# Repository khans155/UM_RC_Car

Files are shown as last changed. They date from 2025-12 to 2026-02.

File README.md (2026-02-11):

# Universal (AC Series) Motor Powered RC Car (Work in Progress)
<p align="center">
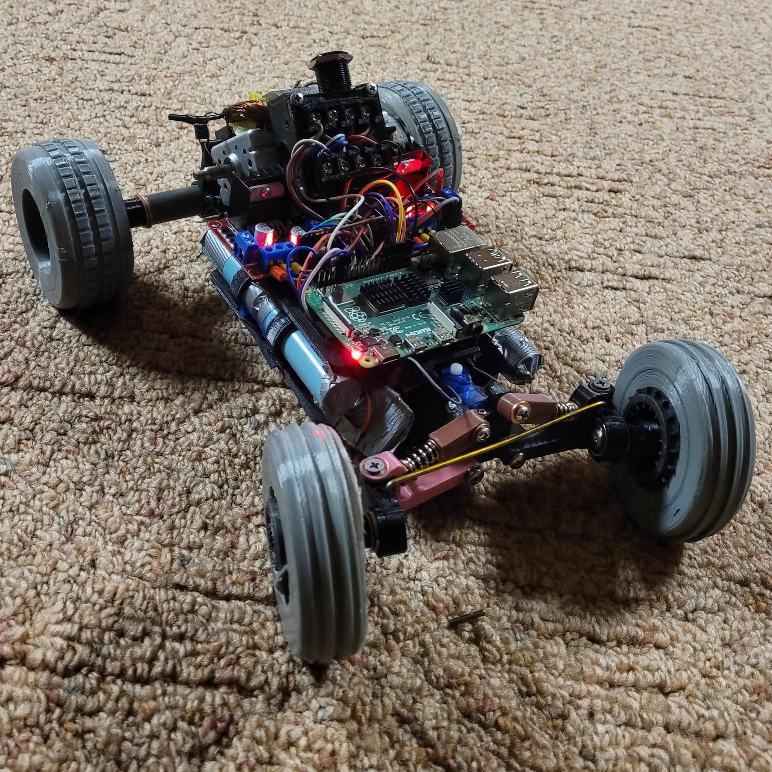
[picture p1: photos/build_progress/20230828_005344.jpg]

  </p>

What motivated me to attempt this project was learning how universal motors are wired. Their wiring allows them to operate on both AC and DC power sources due to the stator and rotor windings being connected in series, though due to this you can't control its direction. However, when these windings are supplied separately from a DC source, it becomes possible to control torque and speed independently. This capability is especially beneficial in situations where high torque is required, such as when a vehicle is stuck against an obstacle and needs additional torque to overcome it.
  
## Motor Control System
The motor control system consists of:
- Two high-current motor driver boards  
- An ESP32 microcontroller  
- A FlySky FS-IA10B receiver and FlySky Remote
- An AC series motor (separate stator and rotor windings)  
- Servo motors for steering  

One motor driver controls the stator windings, while the second driver controls the rotor windings. The ESP32 acts as the control interface between the FlySky receiver and the motor drivers, translating remote inputs into motor speed, torque, and direction commands.
<p align="center">
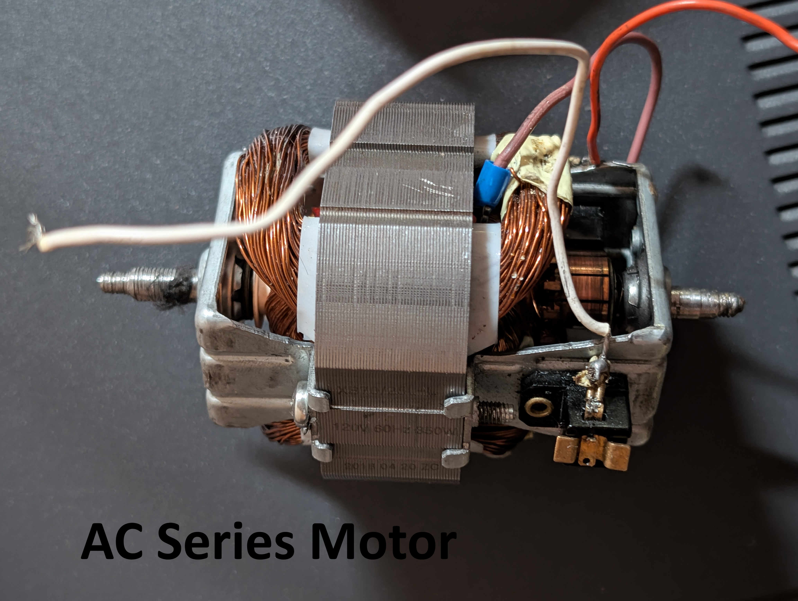
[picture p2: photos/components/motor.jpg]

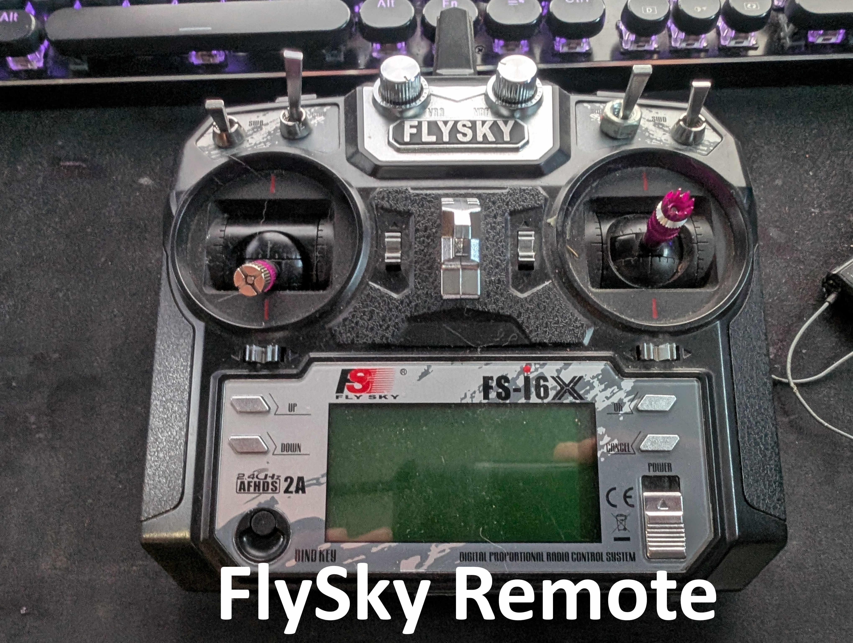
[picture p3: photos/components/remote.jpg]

</p>

The initial design used an L298N motor driver, rated for 3 A. This driver was insufficient for delivering the current required for the speed/torque of the AC series motor for this project.

To address this, the L298N was replaced with the **BTS7960 motor driver**, which is rated for up to 43 A.

Two BTS7960 drivers are used for:
- **Driver 1:** Controls power delivered to the stator windings (torque control)
- **Driver 2:** Controls power and direction of the rotor windings (speed and direction control)

Both drivers are powered by a 25 V Li-ion battery pack.

---

### Rotor Windings (Speed & Direction)
- Primary control of motor speed and direction  
- Direction control via **control pins 40 and 42**
- Speed controlled using a **PWM signal on pin 44** generated by the ESP32

### Stator Windings (Torque Control)
- Used to control motor torque independently of speed
- At low speeds, higher power is supplied to increase torque
- At higher speeds, stator power is reduced to limit current draw

This approach enables independent control of **torque and rotational speed**.
<p align="center">
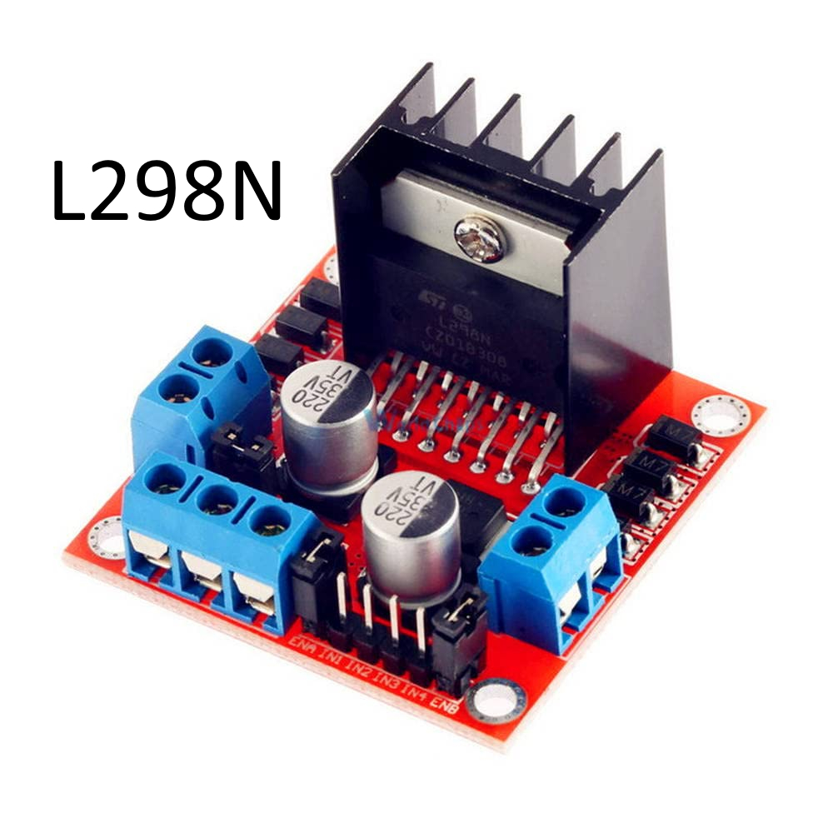
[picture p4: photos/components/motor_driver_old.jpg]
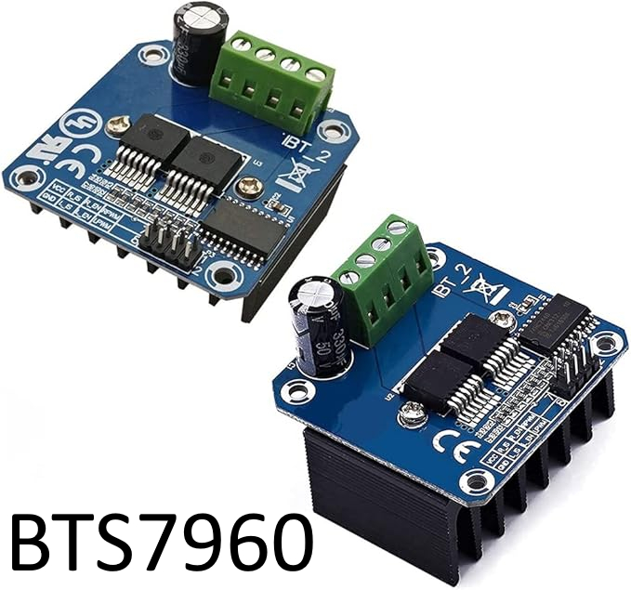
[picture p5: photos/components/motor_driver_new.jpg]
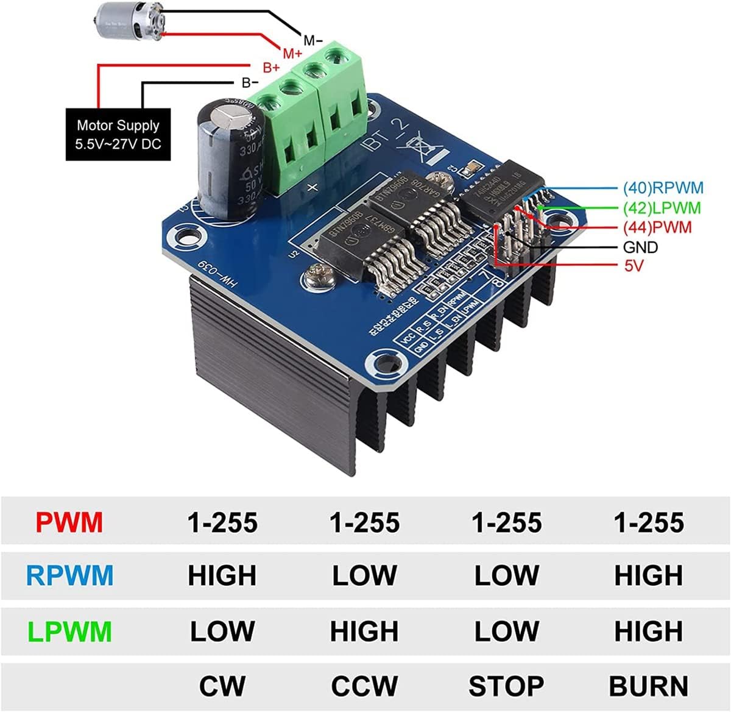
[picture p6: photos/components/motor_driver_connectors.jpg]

</p>

---

The initial system architecture used a Raspberry Pi 4 as an intermediary between the radio receiver and the motor drivers. This was later replaced with an ESP32, as the Raspberry Pi’s additional processing capability and operating system overhead were unnecessary for a real-time motor control application, and also because I fried the Raspberry Pi :). The ESP32 provides a simpler and more deterministic control platform while still offering sufficient performance for signal decoding and PWM generation.

The ESP32 is programmed to receive iBUS serial data from a FlySky FS-IA10B 10-channel 2.5 GHz receiver, which supports both individual PWM outputs and a serial iBUS interface. Communication over this protocol is handled using the IBusBM library. Serial communication is initialized using IBus.begin(Serial2, 1), where pin 1 of the ESP32 is connected to the receiver’s iBUS output.

The FlySky transmitter is configured to transmit the throttle signal on channel 2 of the iBUS stream. This signal is decoded by the ESP32 and converted into appropriate PWM duty cycles for the stator and motor drivers. Channel 5 is mapped to a switch on the transmitter and is used to control motor direction. The ESP32 continuously monitors this channel and reverses motor direction when the switch state changes by actuating the motor driver connected to the rotor windings.

Servo motors are connected directly to the FlySky receiver, as they accept standard PWM signals and therefore do not require any intermediate signal translation.

<p align="center">
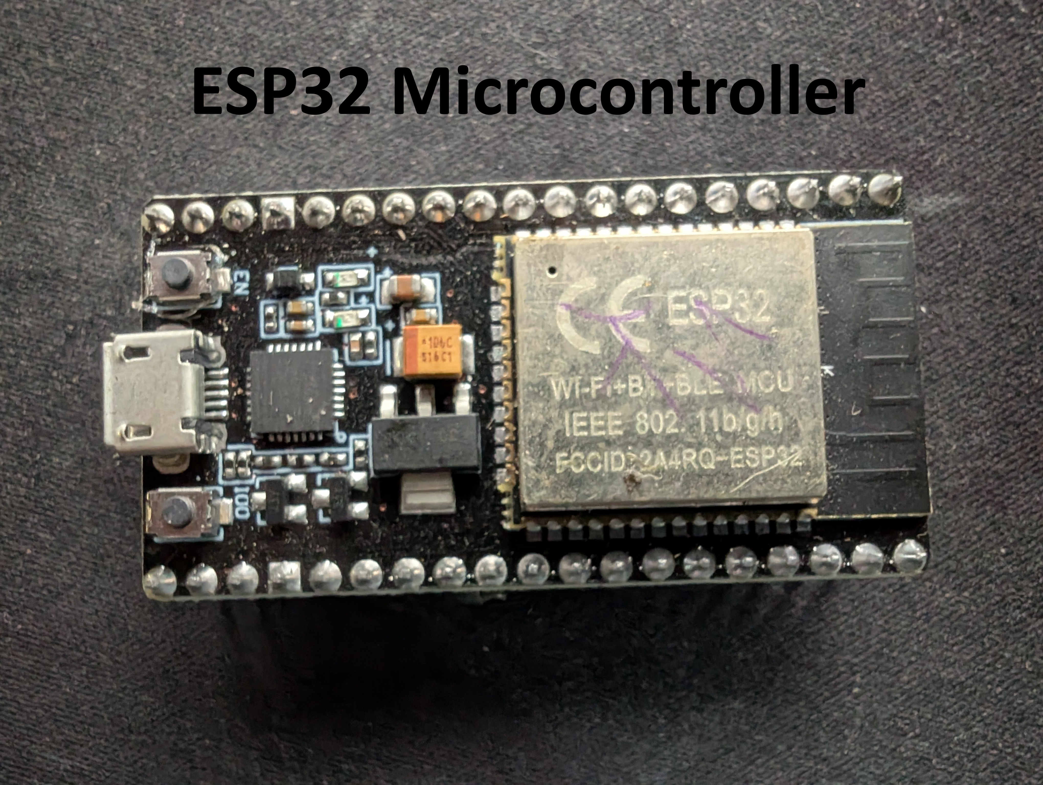
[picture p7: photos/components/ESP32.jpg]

</p>

## Power System (Batteries, Voltage Regulator)
<p align="center">
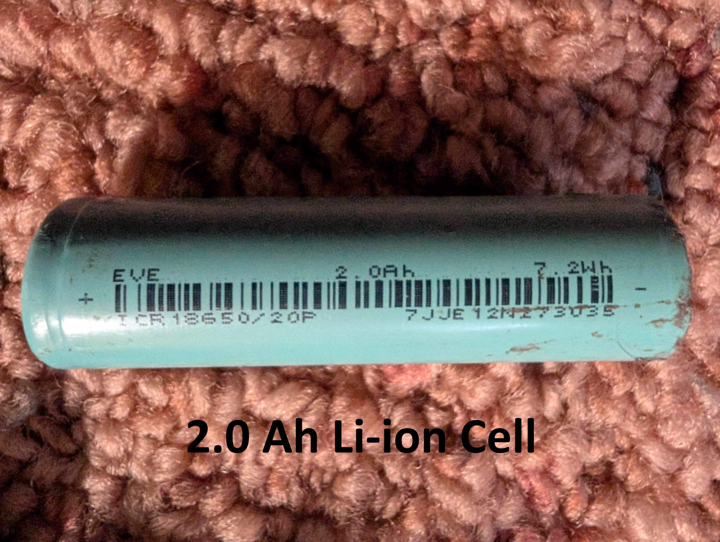
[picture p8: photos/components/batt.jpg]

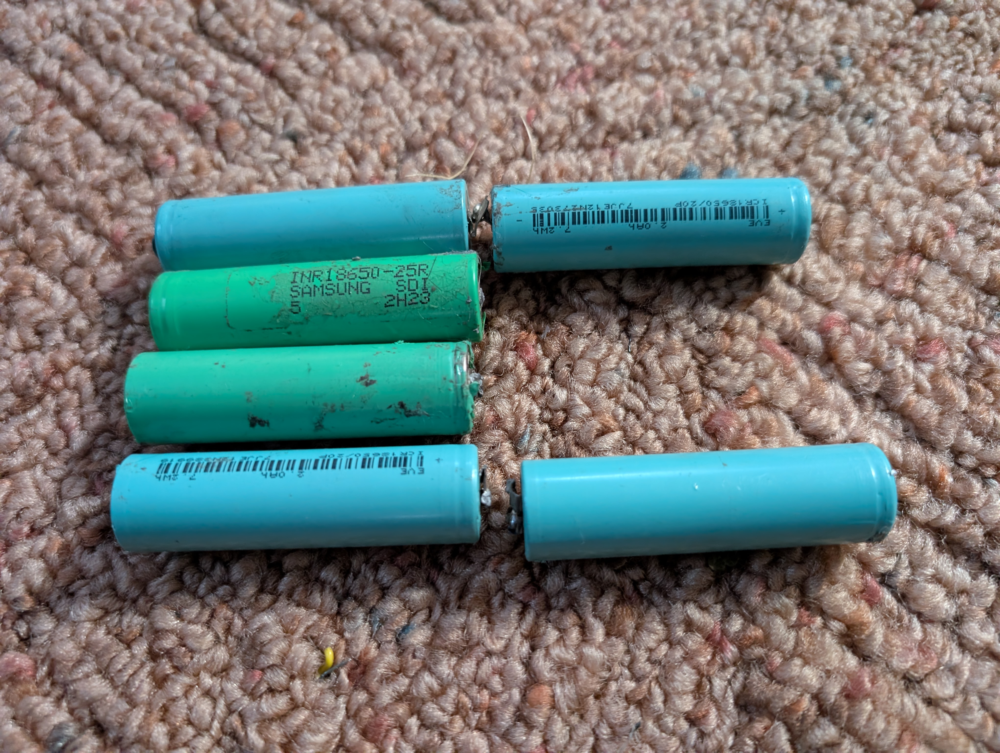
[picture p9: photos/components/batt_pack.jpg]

</p>

<p align="center">
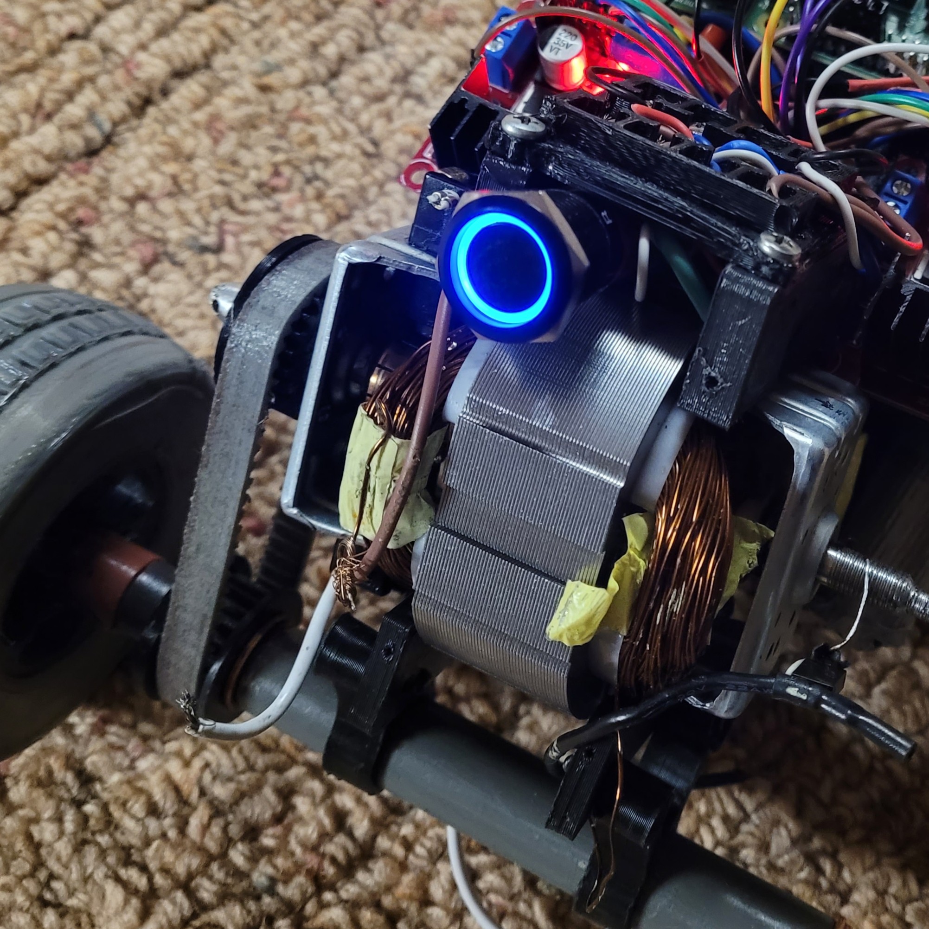
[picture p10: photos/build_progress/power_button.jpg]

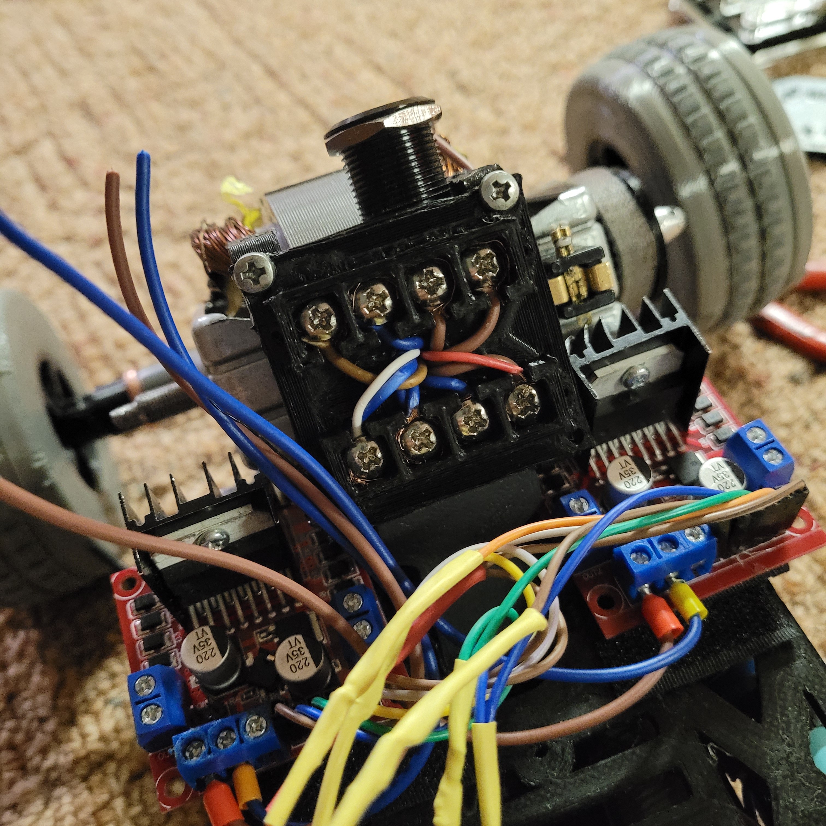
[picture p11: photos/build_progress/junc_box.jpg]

</p>

## 3D Design and Fabrication
<p align="center">
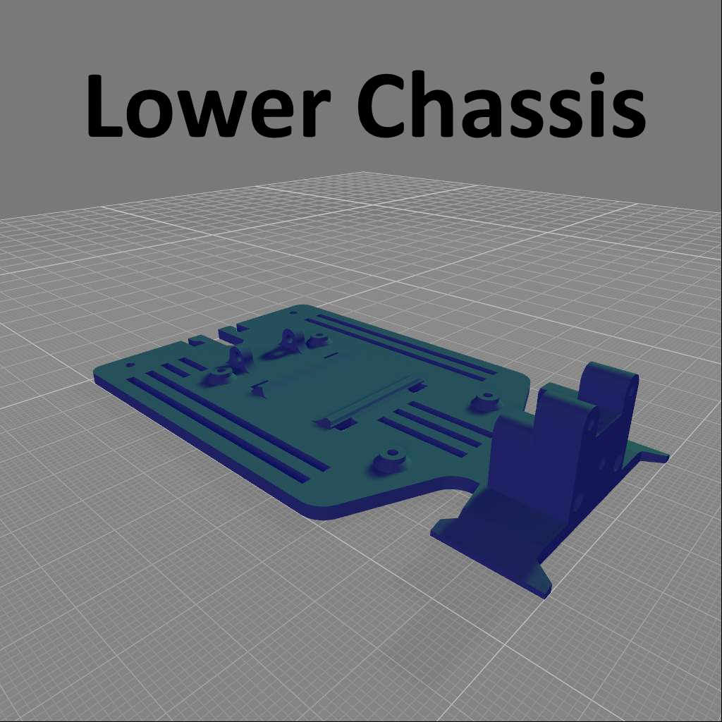
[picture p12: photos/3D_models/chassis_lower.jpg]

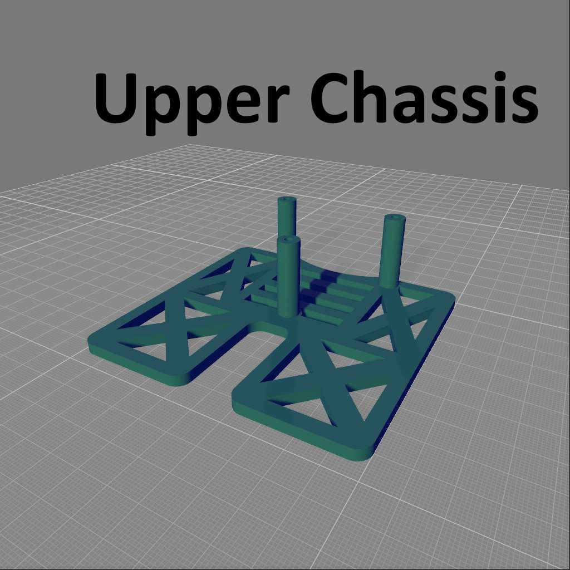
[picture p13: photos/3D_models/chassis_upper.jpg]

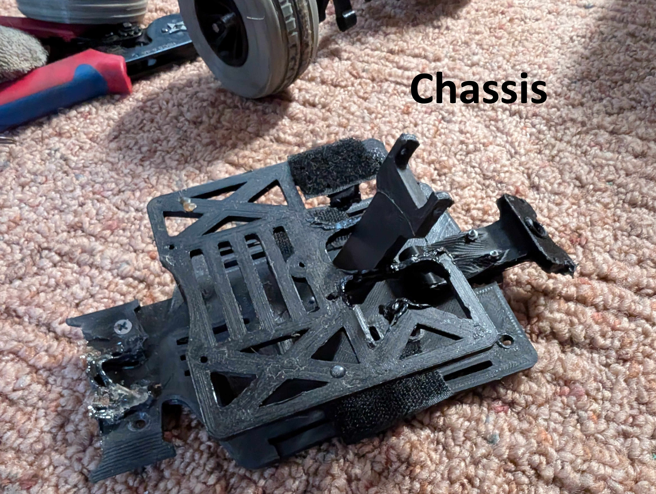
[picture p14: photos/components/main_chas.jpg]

</p>

<p align="center">
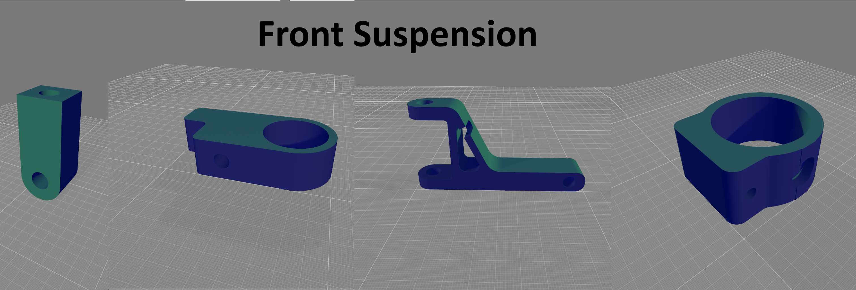
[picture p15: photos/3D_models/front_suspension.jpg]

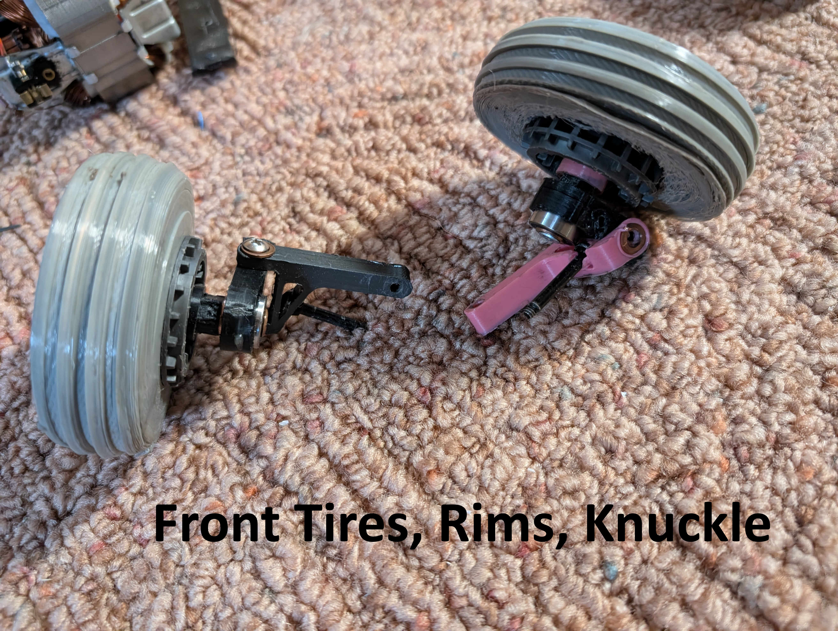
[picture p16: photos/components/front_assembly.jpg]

</p>

<p align="center">
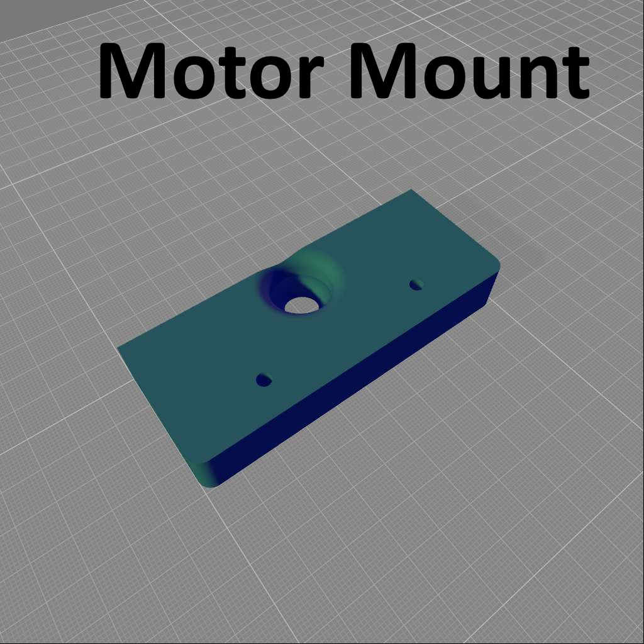
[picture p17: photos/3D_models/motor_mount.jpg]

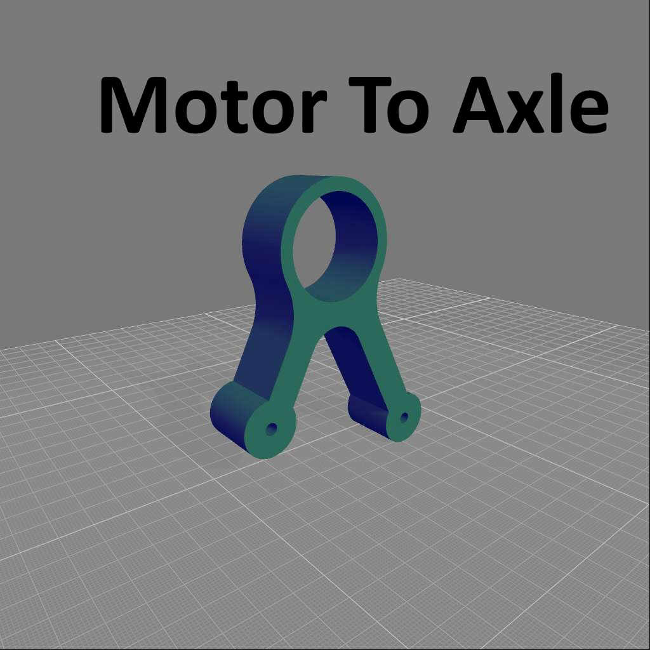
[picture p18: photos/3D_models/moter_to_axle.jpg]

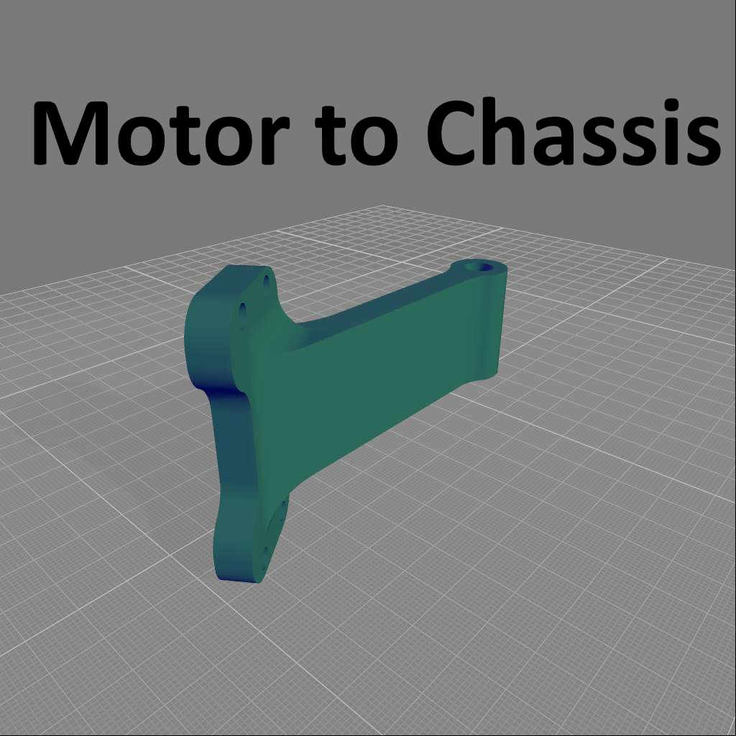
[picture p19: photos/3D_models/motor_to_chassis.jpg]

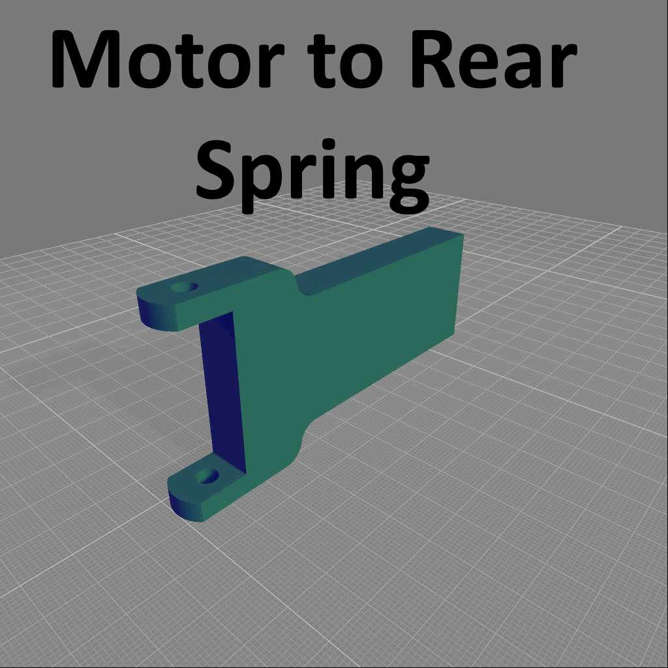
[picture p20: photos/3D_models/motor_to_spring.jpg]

</p>

<p align="center">
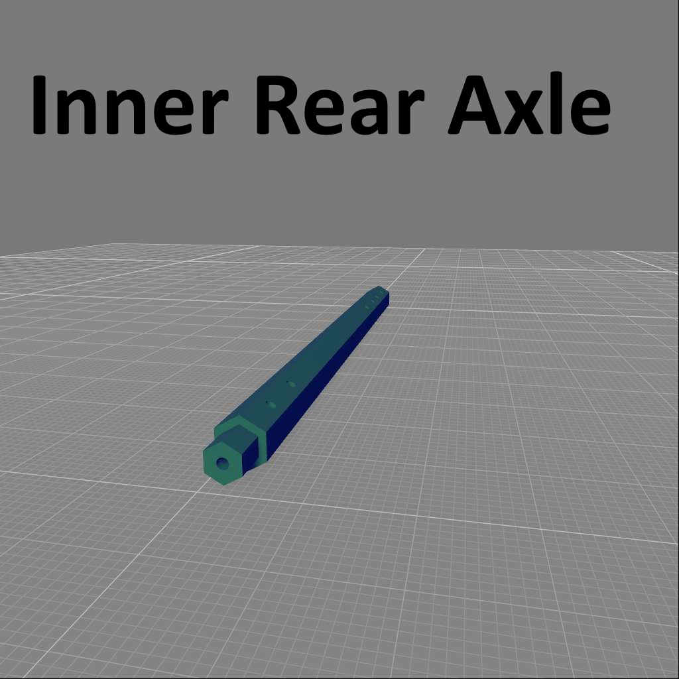
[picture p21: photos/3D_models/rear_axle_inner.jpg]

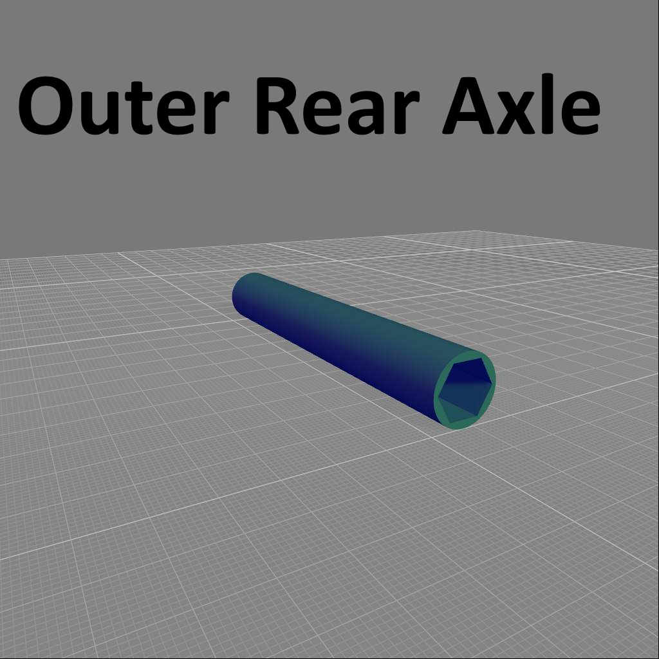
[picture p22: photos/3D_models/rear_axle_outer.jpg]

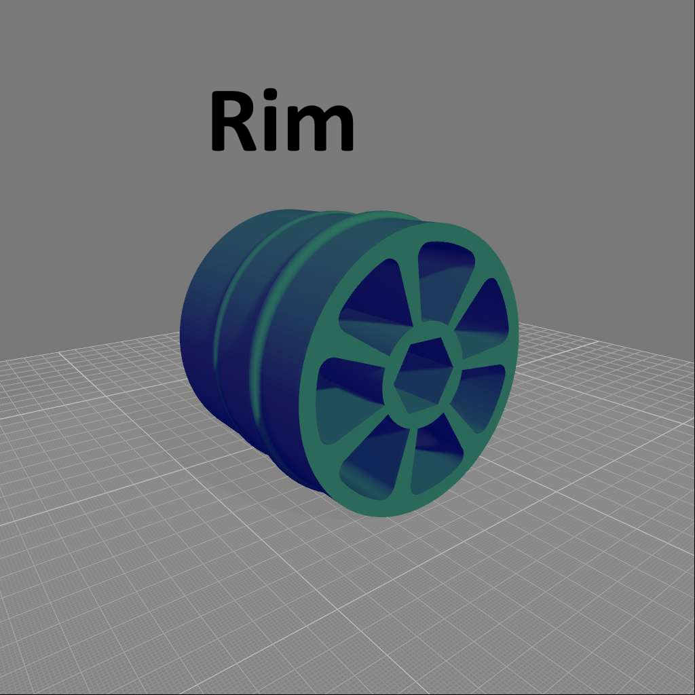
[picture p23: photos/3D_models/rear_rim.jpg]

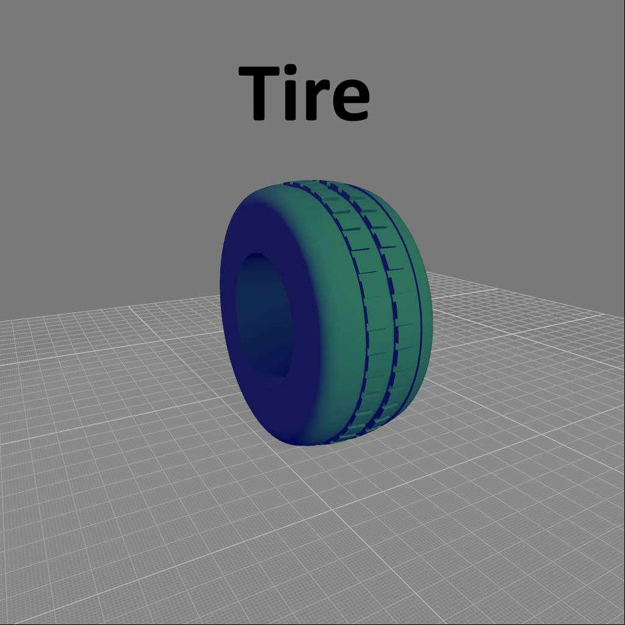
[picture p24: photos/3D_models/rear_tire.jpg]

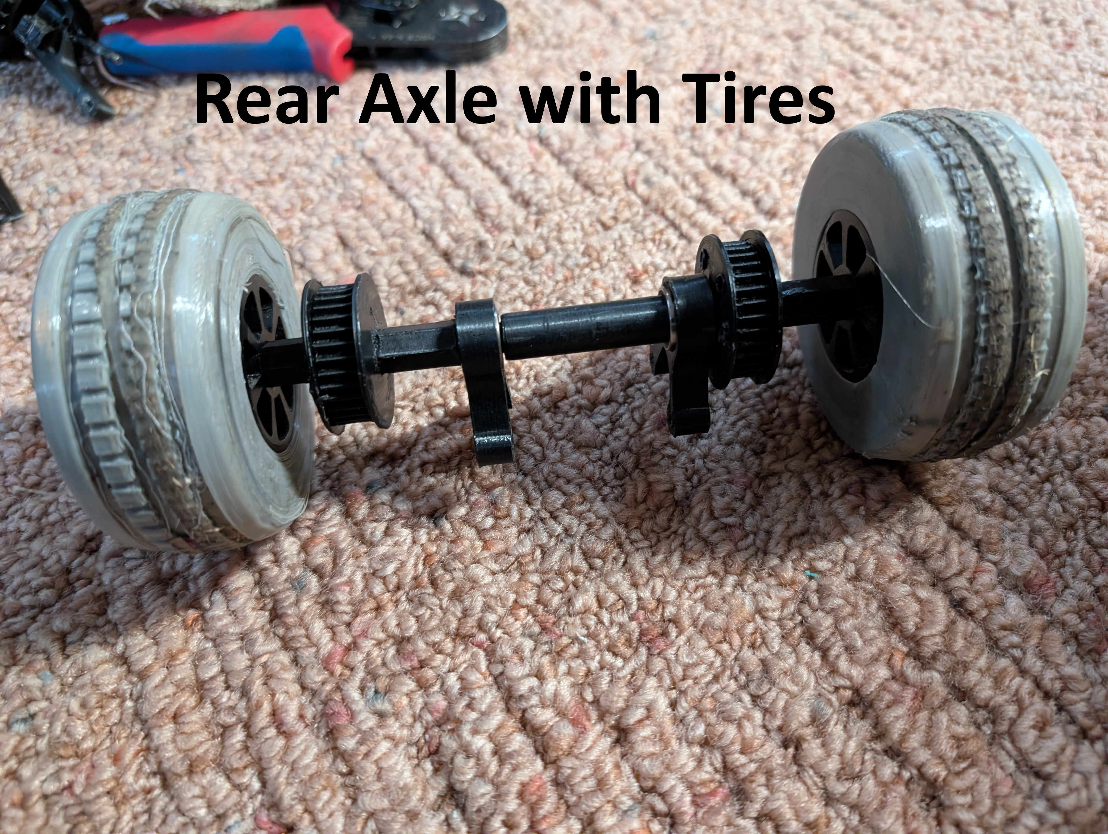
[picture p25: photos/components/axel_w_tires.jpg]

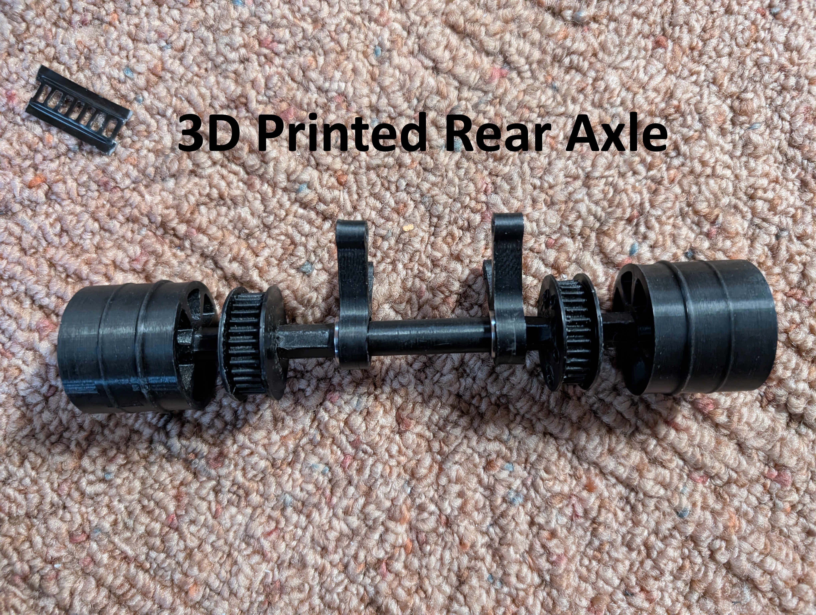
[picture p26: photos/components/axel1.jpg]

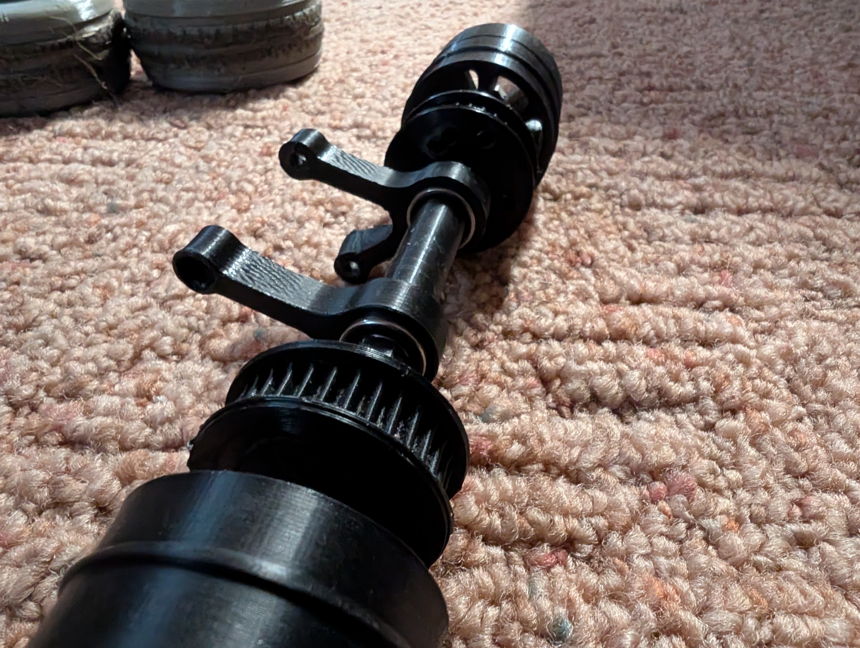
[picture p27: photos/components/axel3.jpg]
  
</p>

<p align="center">
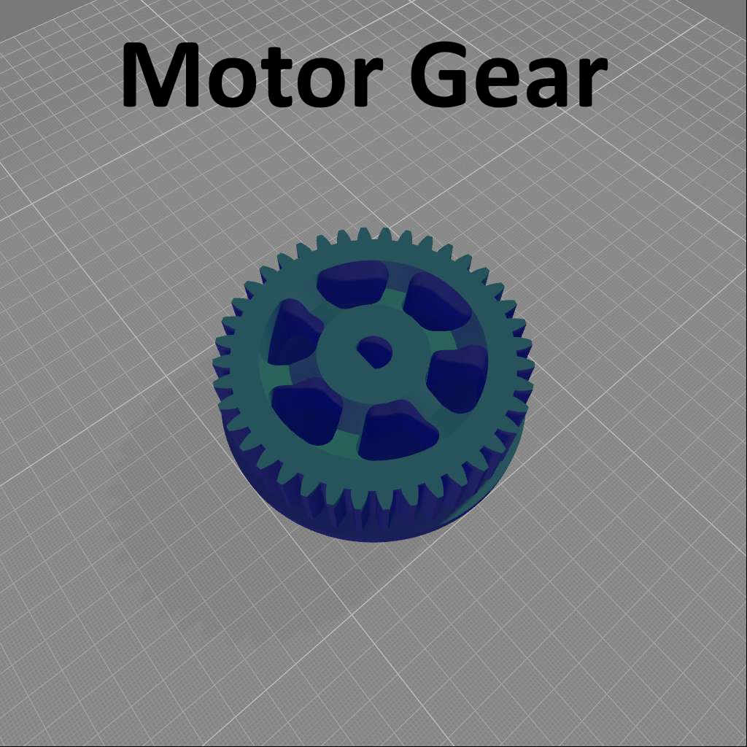
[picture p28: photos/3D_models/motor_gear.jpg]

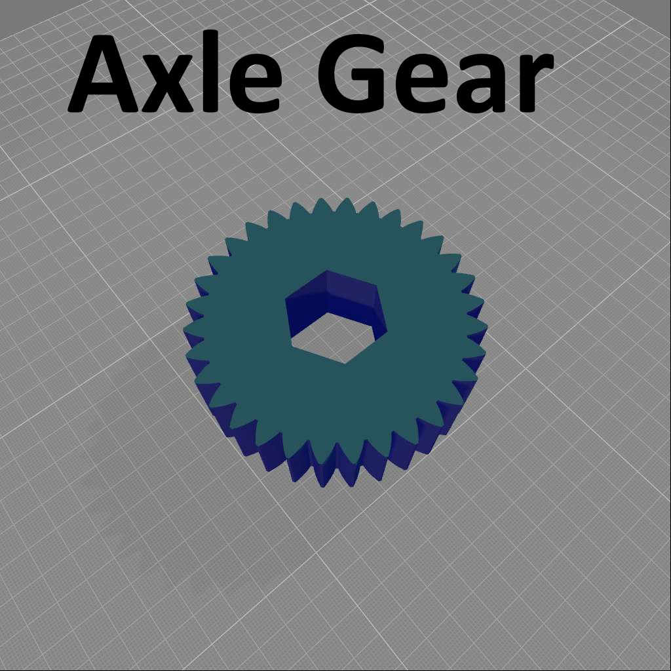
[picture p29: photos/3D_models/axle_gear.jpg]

</p>

## Progress Photos
<p align="center">


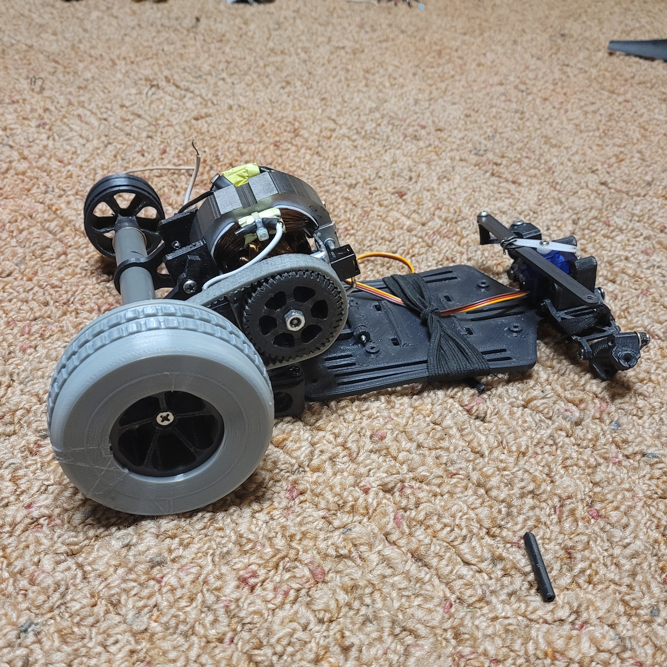
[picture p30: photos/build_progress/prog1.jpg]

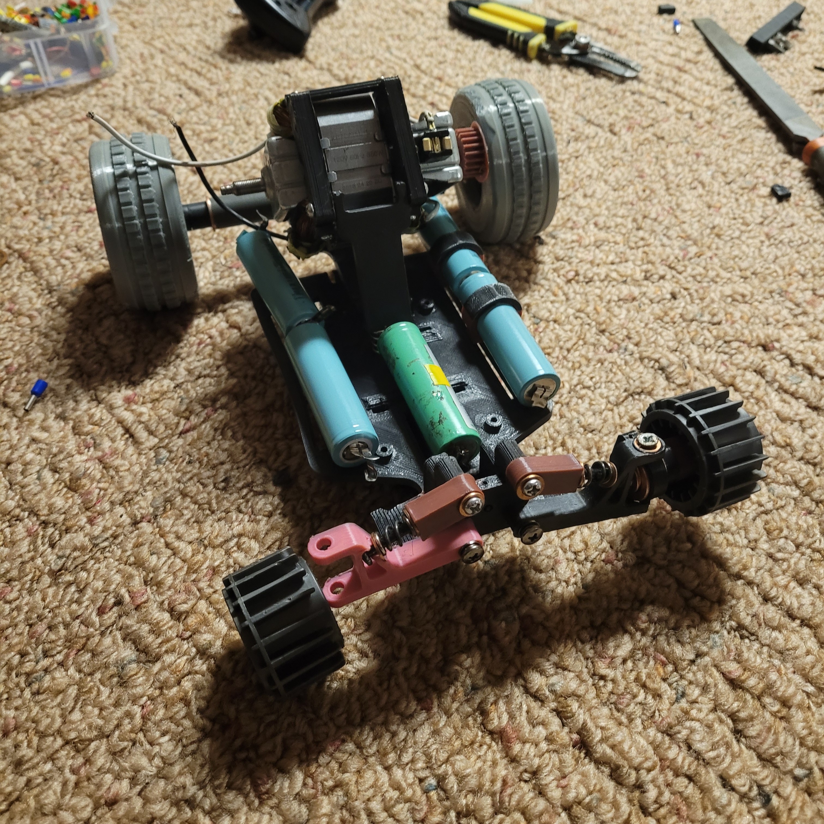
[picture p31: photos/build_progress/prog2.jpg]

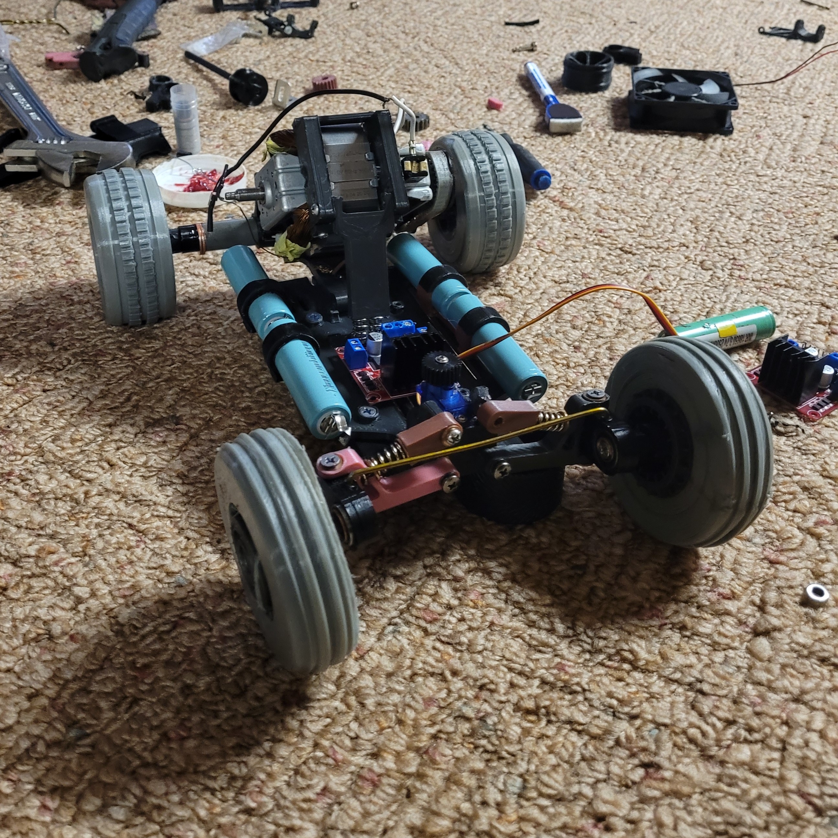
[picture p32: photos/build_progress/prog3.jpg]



</p>

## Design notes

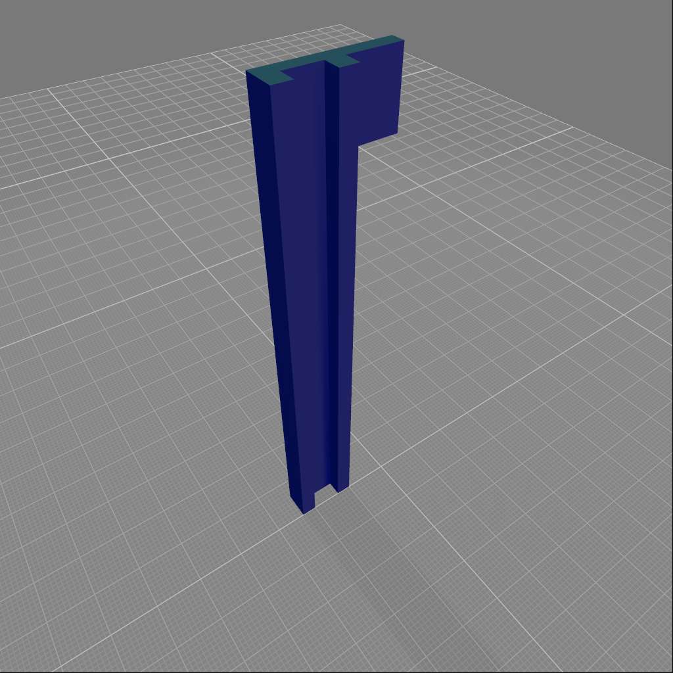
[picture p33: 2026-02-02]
photos/3D_models/chassis_reinforcement.jpg

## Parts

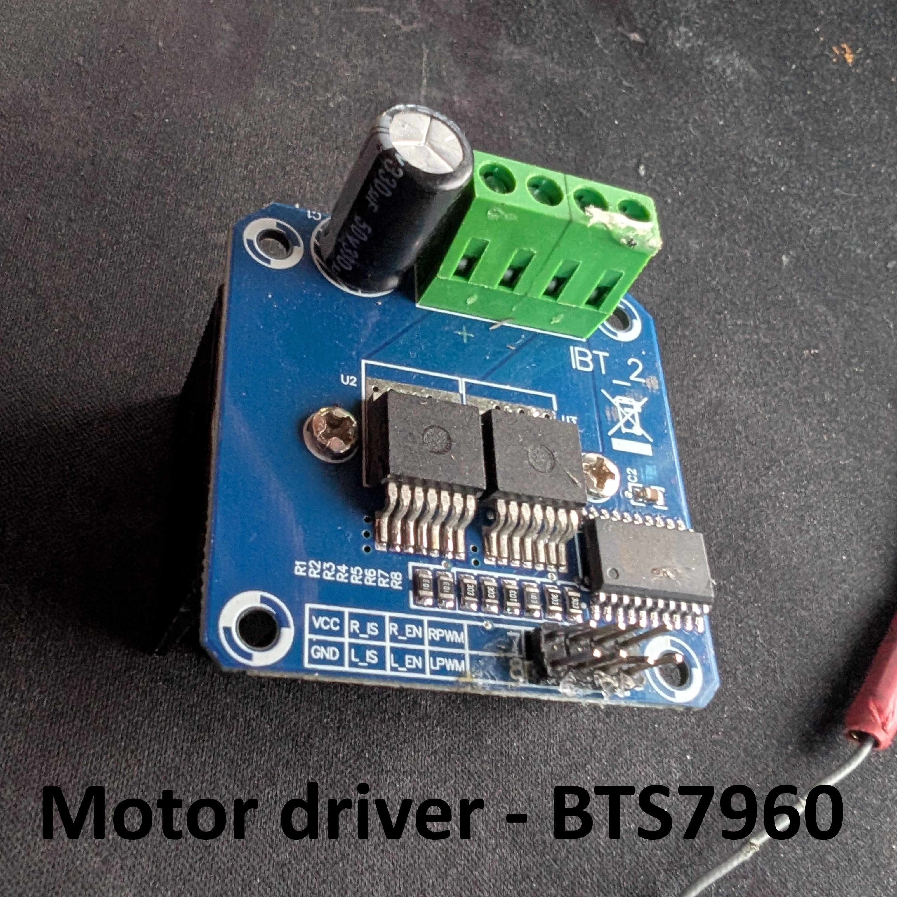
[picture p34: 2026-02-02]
photos/components/motor_driver.jpg

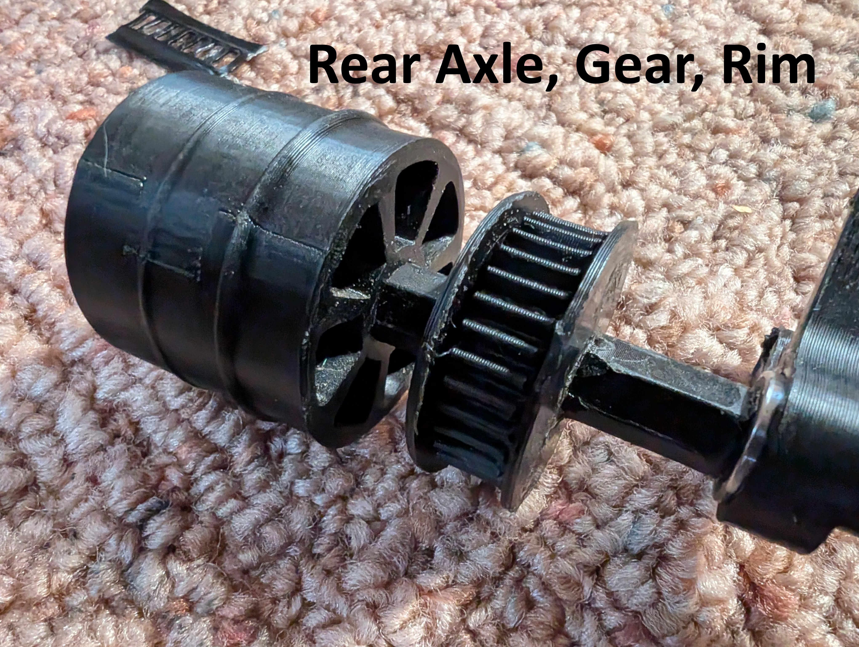
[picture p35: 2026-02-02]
photos/components/axel2.jpg

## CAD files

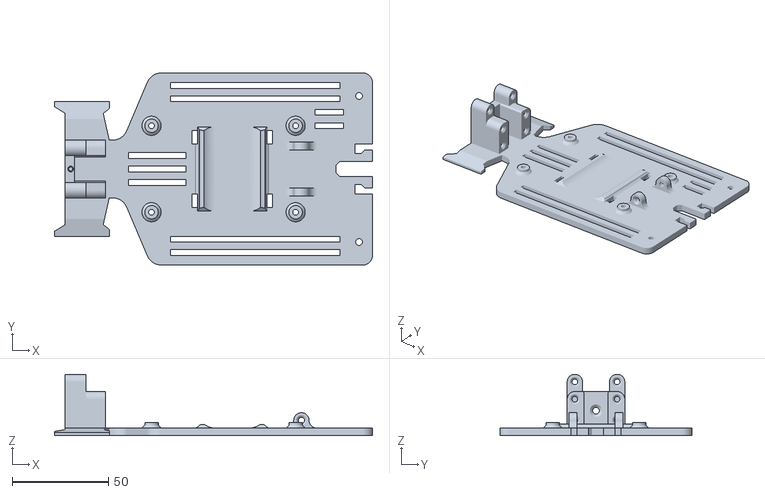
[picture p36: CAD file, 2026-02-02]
3d_models/chassis_lower.stl
165.5 x 100.0 x 32.0

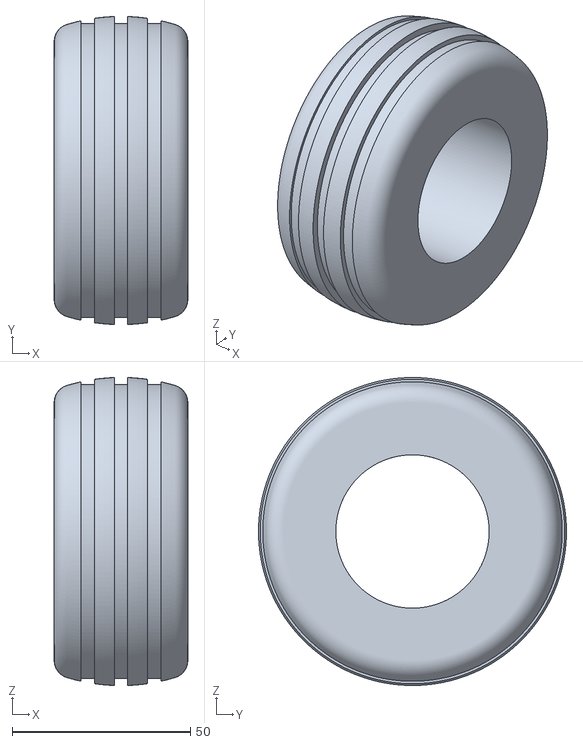
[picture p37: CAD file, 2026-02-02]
3d_models/front_tire.stl
37.5 x 86.4 x 86.4

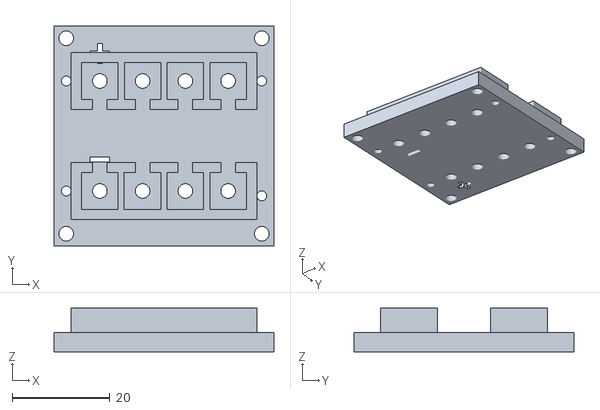
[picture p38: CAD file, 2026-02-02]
3d_models/junction_box.stl
45.0 x 45.0 x 9.00

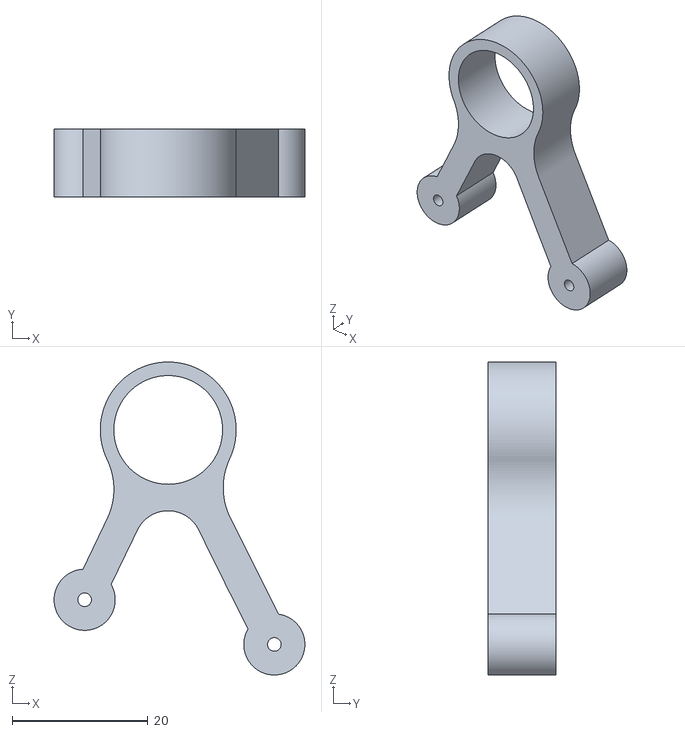
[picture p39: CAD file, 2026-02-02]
3d_models/motor_to_axle.stl
36.9 x 10.0 x 46.1

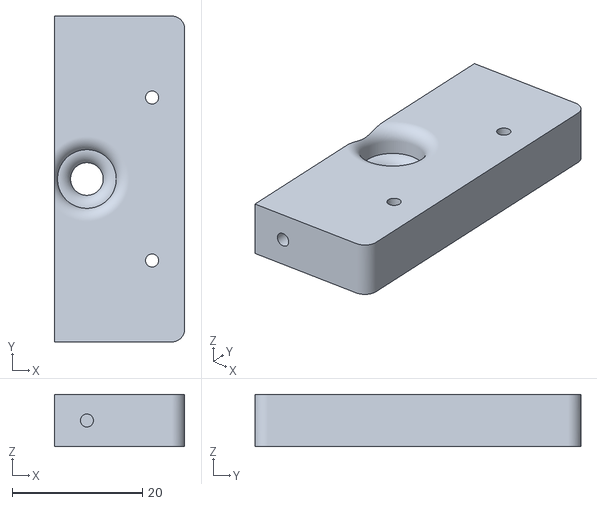
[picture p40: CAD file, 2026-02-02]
3d_models/motor_mount.stl
20.0 x 50.0 x 8.00

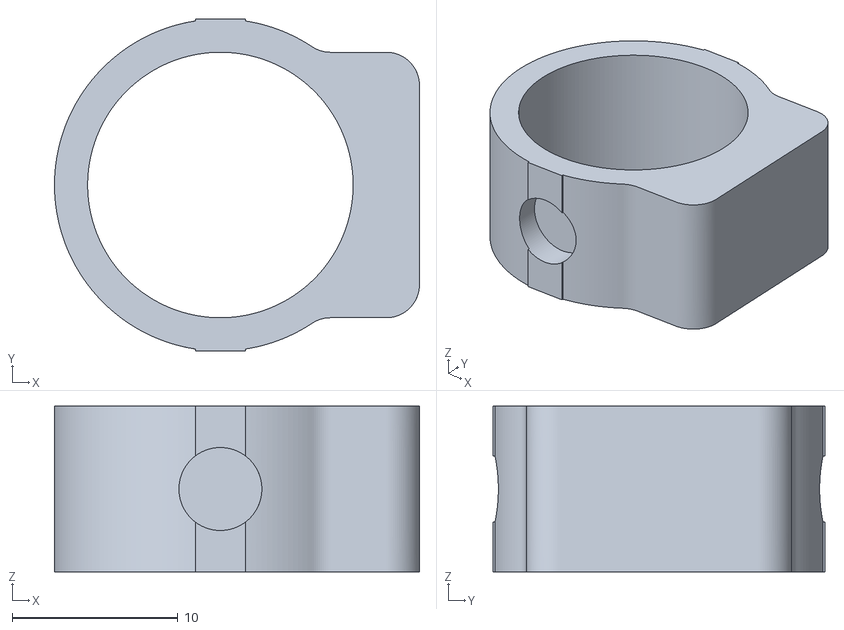
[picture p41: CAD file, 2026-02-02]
3d_models/front_suspension_3.stl
22.0 x 20.0 x 10.0

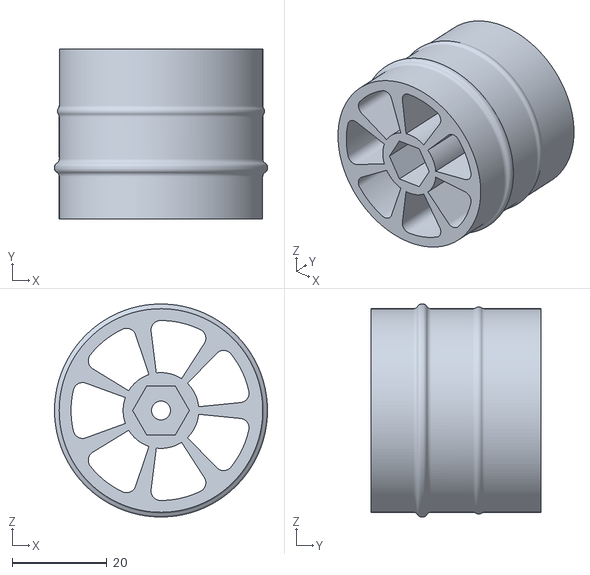
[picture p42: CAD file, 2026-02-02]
3d_models/rim.stl
45.0 x 36.0 x 45.0

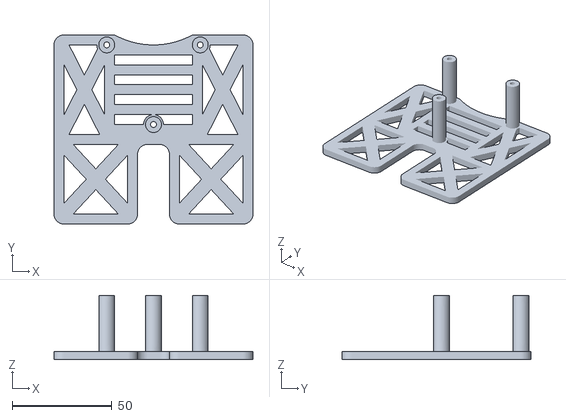
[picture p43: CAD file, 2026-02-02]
3d_models/chassis_upper.stl
100.0 x 95.0 x 32.2

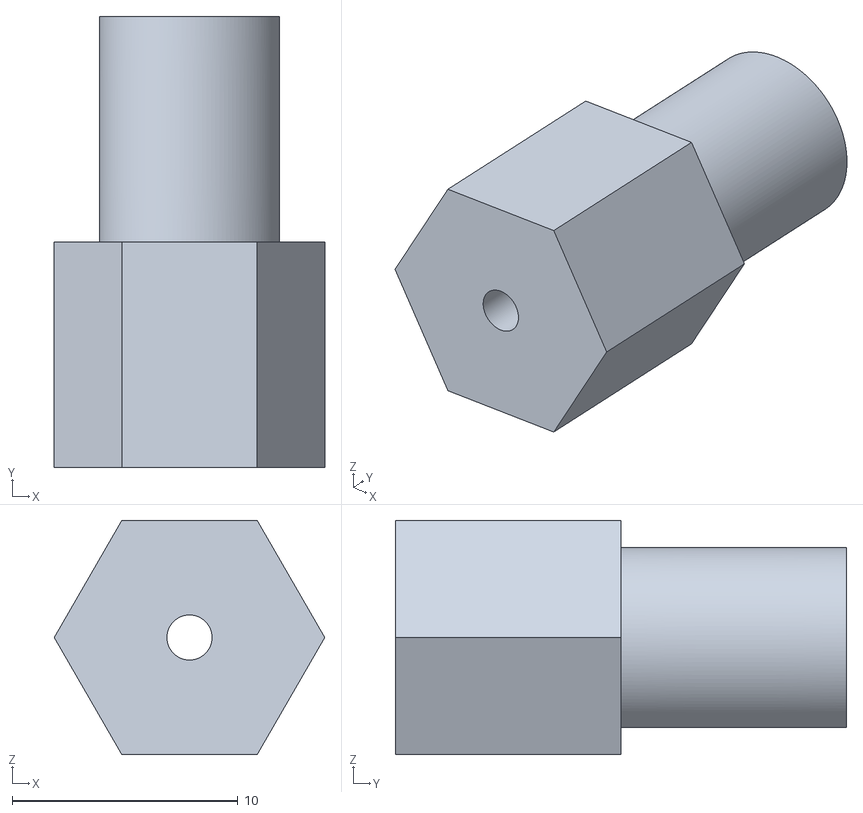
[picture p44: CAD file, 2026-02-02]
3d_models/front_axle.stl
12.0 x 20.0 x 10.4

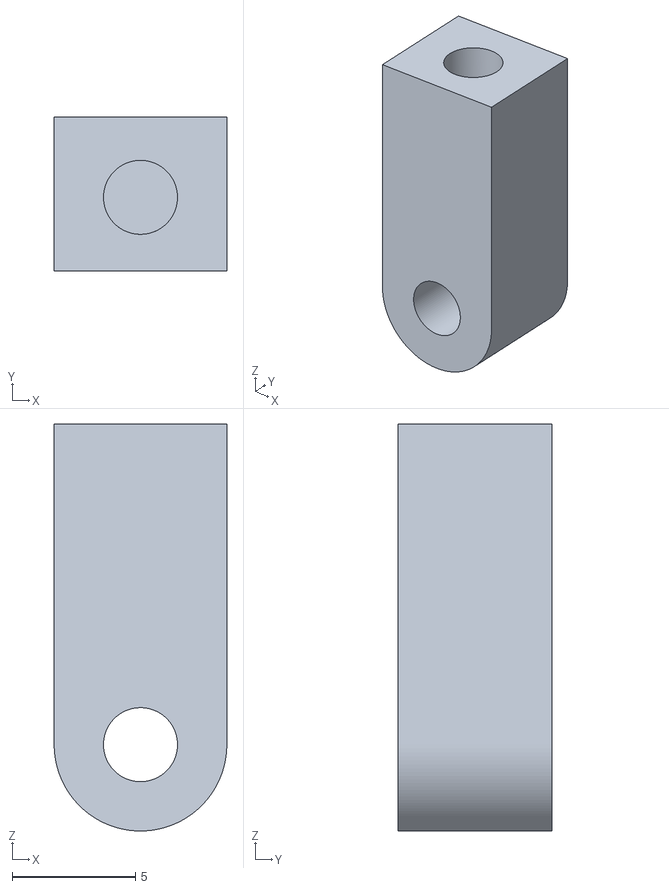
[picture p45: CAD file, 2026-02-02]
3d_models/suspension_to_spring.stl
7.00 x 6.25 x 16.5

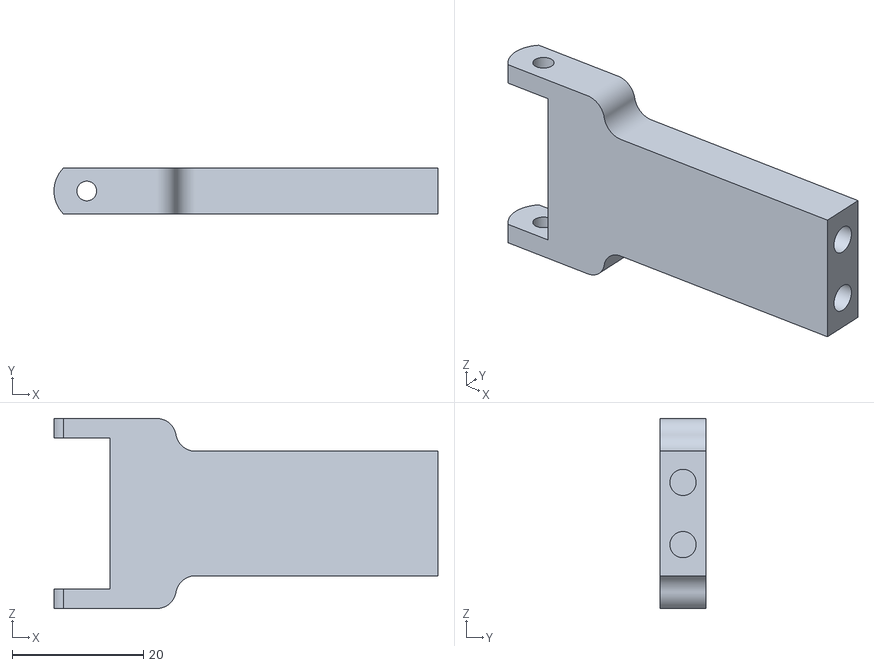
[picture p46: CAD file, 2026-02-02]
3d_models/motor to spring.stl
58.6 x 7.00 x 29.0

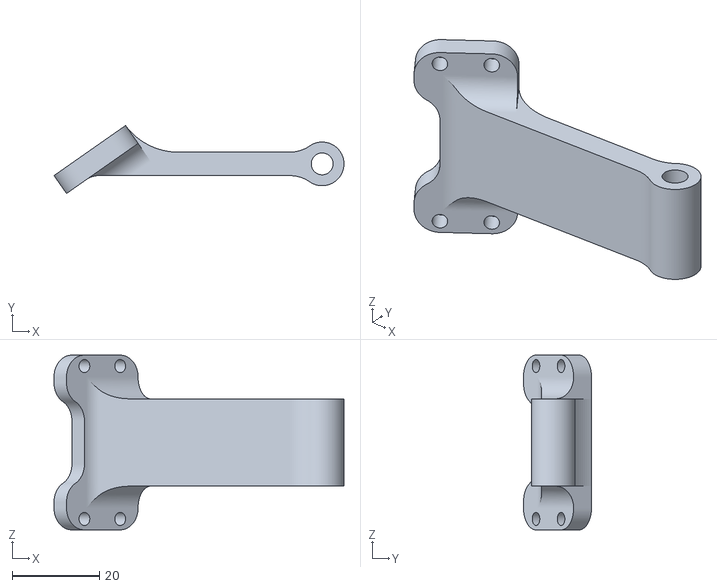
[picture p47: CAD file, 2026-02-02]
3d_models/motor to frame.stl
66.4 x 15.6 x 40.0

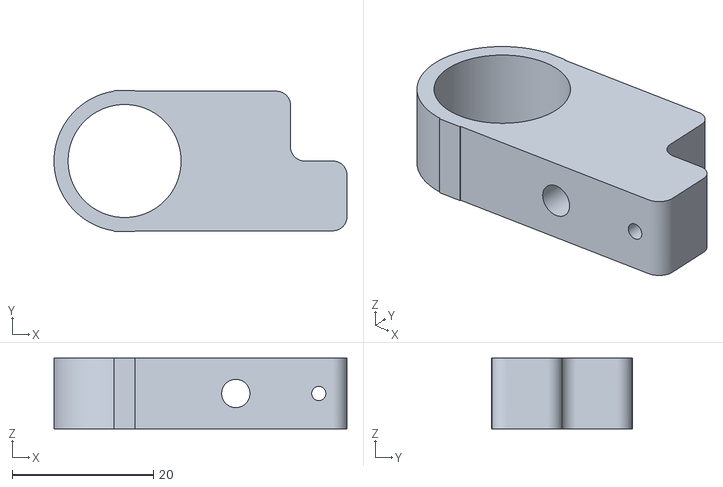
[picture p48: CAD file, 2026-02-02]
3d_models/front_suspension_1.stl
41.5 x 20.0 x 10.0

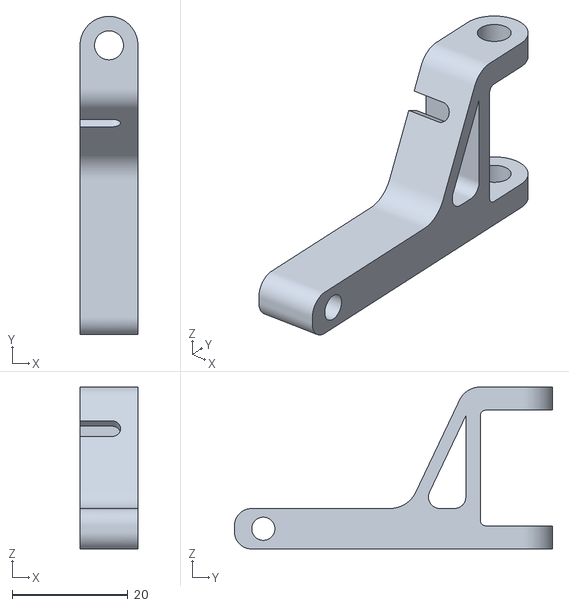
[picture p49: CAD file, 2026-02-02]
3d_models/front_suspension_2.stl
10.0 x 55.0 x 28.0

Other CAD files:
3d_models/rear_axle_outer.stl
3d_models/axle_gear.stl
3d_models/motor_gear.stl
3d_models/battery_mount.stl
3d_models/bearing_adapter.stl
3d_models/rear_axle_inner.stl
3d_models/rear_tire.stl

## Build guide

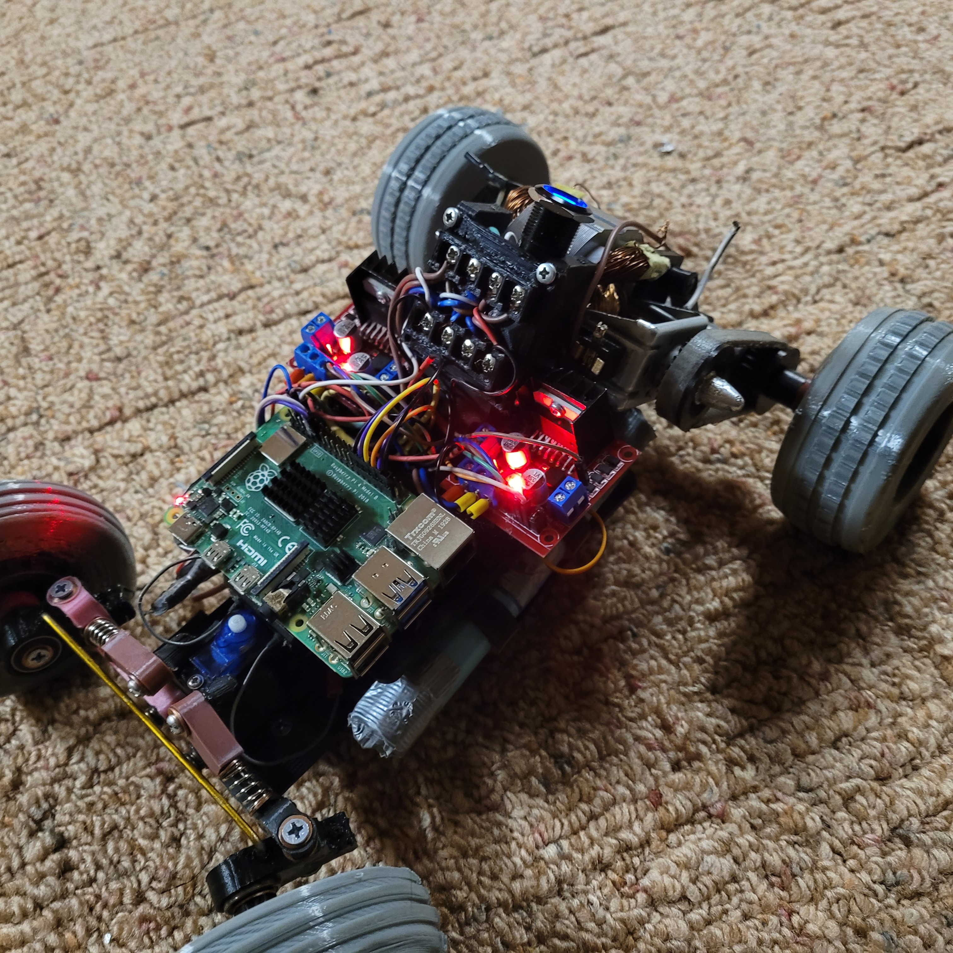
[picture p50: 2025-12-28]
photos/build_progress/20230828_005507.jpg

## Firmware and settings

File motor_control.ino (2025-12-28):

#include <IBusBM.h>

//OUTPUT pins 
#define coil1 27
#define coil2 26
#define PWM_coil 12
#define brush1 25
#define brush2 33
#define PWM_brush 14

//PWM parameters
#define PWM_res  8
#define PWM_freq  10000 

IBusBM IBus;    // IBus object

void setup() {
  IBus.begin(Serial2,1);
  Serial.begin(115200);

  //Motor direction set pins
  pinMode(coil1, OUTPUT);
  pinMode(coil2, OUTPUT);
  pinMode(brush1, OUTPUT);
  pinMode(brush2, OUTPUT);
  digitalWrite(coil1, HIGH);
  digitalWrite(coil2, LOW);
  digitalWrite(brush1, HIGH);
  digitalWrite(brush2, LOW);

  //PWM PIN SETUP
  ledcAttachPin(PWM_coil, 0);
  ledcSetup(0, PWM_freq, PWM_res);
  ledcAttachPin(PWM_brush, 1);
  ledcSetup(1, PWM_freq, PWM_res);

}

void loop() {
  int val;
  int duty;
  int duty_brush;
  int duty_coil;
  

  //Reading throttle from reciever and calculating duty cycle
  val = IBus.readChannel(2);
  duty = (val-1000)/10;
  if (duty > 2) {
    duty_brush = 10 + 70*duty/100;
    duty_coil = 100 - duty_brush;
  }
  else{
    duty_brush = 0;
    duty_coil = 0;
  }
  //Assigning duty cycle to output pwm pins
  ledcWrite(0, duty_coil*255/100);
  ledcWrite(1, duty_brush*255/100);

  //Direction of Motor
  if (IBus.readChannel(5)>1500){
    digitalWrite(brush1, LOW);
    digitalWrite(brush2, HIGH);
  }else{
    digitalWrite(brush1, HIGH);
    digitalWrite(brush2, LOW);
  }
  
}

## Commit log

2026-02-02 Enhance Motor Control System details in README
    Expanded the Motor Control System section to detail components, functionality, and changes made to the motor driver and microcontroller. Updated information about the ESP32 and its communication with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
2026-02-02 Revise motor driver details and image formatting
    Updated image widths and replaced L298N driver with BTS7960 in the README.
2026-02-02 Revise motor control system details in README
    Updated the README to reflect changes in motor driver specifications and connections.
2026-02-02 Revise README for motor control system details
    Updated image description and clarified motor driver specifications.
2026-02-02 Revise README for motor control system details
    Updated motor control system description and image caption.
2026-02-02 Enhance README with motor driver details and image
    Updated motor control system description and added figure caption.
2026-02-02 Revise README with motor driver information
    Updated motor control system details and images.
2026-02-02 Revise README with ESP32 details and image updates
    Updated images and clarified the use of ESP32 in the system.
2026-02-02 stl and more pics added
    [axle_gear.stl, battery_mount.stl, bearing_adapter.stl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]
2026-02-03 Enhance README with detailed motor control system info
    Expanded the motor control system section to include detailed descriptions of components, their functions, and the changes made to improve performance. Updated the architecture explanation to reflect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
2026-02-03 Revise system architecture description for ESP32
    Updated the README to reflect the change from Raspberry Pi to ESP32 for motor control.
2026-02-11 Refine README content for motor control project
    Updated text for clarity and conciseness in the README.
